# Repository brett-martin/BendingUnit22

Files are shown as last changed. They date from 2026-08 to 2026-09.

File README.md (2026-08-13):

# Bending Unit 22

BU-22 is a modular animatronic Bender-inspired clock and character display.
The Brain orchestrates operating modes, sensors, time, audio, and user input.
Independent Eyes and Mouth controllers own their LED hardware, rendering, and
precisely timed local animations.

This repository currently contains the proven Brain/Eyes breadboard tests,
draft display protocol, experimental content catalogs, and first clean v0
CircuitPython firmware slice.

## Repository map

```text
BU22_Brain/
  firmware/v0/          First Brain protocol exerciser
  tests/                Feather smoke test and reusable I2C validation suite

BU22_Eyes/
  catalogs/             Experimental expressions, animations, performances
  firmware/v0/          First clean Eyes firmware slice
  tests/                Universal I2C receiver and hardware-test backups

BU22_Mouth/
  README.md             Mouth subsystem placeholder

protocol/
  semantic_protocol_v0.md   Behavior, terminology, and ownership
  wire_protocol_v0.md       Concrete draft I2C encoding
  commands.md               Raw breadboard-only validation bytes
```

The original six-channel electrical bring-up programs are preserved under the
named Brain and Eyes test folders rather than serving as production firmware.

## Current breadboard hardware

- Adafruit Feather RP2040 acting as Brain
- Adafruit KB2040 acting as Eyes controller
- Six independent four-pixel SK9822 strands
- Three 74AHCT125 level-shifter ICs
- Independent USB power for both MCUs during development
- External regulated 5 V for level shifters and LEDs
- Shared ground, SDA, and SCL
- 4.7k I2C pull-ups to the Brain's 3.3 V rail
- Qwiic red power conductor disconnected during independent USB testing

### Eyes channel pin map

| Channel | Data | Clock |
|---:|---:|---:|
| 1 | D2 | D3 |
| 2 | D4 | D5 |
| 3 | D6 | D7 |
| 4 | D8 | D9 |
| 5 | D10 | A0 |
| 6 | A1 | A2 |

The current test assembly is physically rotated 180 degrees. Firmware keeps
content in logical orientation and applies the hardware transform at render
time.

## Proven functionality

- I2C discovery at Eyes address `0x30`
- One-byte and parameterized multi-byte commands
- Global brightness control
- Independent six-channel and 24-pixel control
- Complete 25-byte frame streaming at 10 FPS with no late frames
- Bidirectional status readback under display traffic
- Locally stored expressions and animations
- Immediate Brain interruption and STOP
- Dedicated Visor Down/Up row transitions
- Brain and Eyes disconnect/reconnect recovery
- Five-second standalone Normal fallback
- Visible missing-content development errors
- Concise action-level Eyes serial logging

See [the I2C validation index](BU22_Brain/tests/i2c_validation/README.md)
for the reusable development-board test sequence.

## Content catalogs

Expressions, animations, and performances use separate numeric ID spaces.
They remain experimental before v1. At v1, reviewed IDs become stable; later
content is appended while existing entries may improve without changing their
semantic meaning.

See [the Eyes catalog rules](BU22_Eyes/catalogs/README.md).

## Protocol documents

- [Semantic protocol v0](protocol/semantic_protocol_v0.md)
- [Wire protocol v0](protocol/wire_protocol_v0.md)
- [Raw hardware-validation commands](protocol/commands.md)

The semantic and wire documents are drafts. The raw validation bytes remain
separate so future hardware can rerun today's proven tests regardless of how
the production protocol evolves.

## Running the v0 Brain/Eyes slice

On the KB2040 Eyes `CIRCUITPY` drive, copy:

```text
BU22_Eyes/firmware/v0/code.py
BU22_Eyes/firmware/v0/config.py
BU22_Eyes/firmware/v0/content.py
```

Its `lib` directory also needs:

```text
adafruit_dotstar.mpy
adafruit_pixelbuf.mpy
```

On the Feather RP2040 Brain `CIRCUITPY` drive, copy:

```text
BU22_Brain/firmware/v0/code.py
```

The exerciser cycles expressions and animations, interrupts an animation,
tests Off and visor transitions, requests missing animation `999`, reads the
error status, and recovers with Normal.

## CircuitPython dependencies

Install the DotStar CircuitPython dependencies with:

```sh
python3 -m circup install -r requirements.txt
```

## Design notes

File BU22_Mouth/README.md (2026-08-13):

# BU-22 Mouth

The Mouth will be an independent I2C-controlled display subsystem. Its first
hardware and protocol tests will be added after the Brain-to-Eyes I2C path is
proven. Address `0x31` is reserved for it.

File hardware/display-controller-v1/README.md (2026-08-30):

# BU-22 Universal Display Controller V1

This is the hand-assembled prototype controller for either the BU-22 eyes or
mouth. Two identical boards are intended for the first complete bench system.
Pixel hardware is external: six independent SK9822/APA102-compatible LED
strings connect through four-pin JST-XH cables.

## Prototype goals

- Validate full, pixel-accurate eye and mouth animations before ordering dense
  assembled LED PCBs.
- Keep expensive LED assemblies electrically simple and reusable.
- Use through-hole parts wherever practical so five bare PCBs can be ordered
  and at least two assembled by hand.
- Keep display power distribution outside the Brain. The controller receives a
  fused 5 V branch and distributes it to its six display connectors.
- Remain usable as either Eyes (`0x30`) or Mouth (`0x31`) by changing one
  address jumper.

## Board envelope and placement

- Two-layer FR-4, 140 mm x 65 mm, with lightly rounded 3 mm corners.
- Four M3 mounting holes, 5 mm from each corner.
- Six outward-facing JST-XH outputs along the top edge.
- 5 V screw terminal, local bulk capacitors, power LED, and KB2040 USB access
  on the left side.
- Heartbeat indicator, TEST, and RESET controls along the lower-left edge.
- Four-position address selection and I2C connections along the lower edge.
- No components or connectors on the bottom side.
- Right-side silkscreen equipment mark: `BENDING UNIT 22`, `DISPLAY CONTROL
  MODULE`, and canonical serial number `2716057`, accompanied by a small
  heart/smile factory emblem no larger than the 10 mm bulk capacitor.

The 65 mm height is provisional. It fits inside the approximately 75 mm visor
opening with more than 5 mm clearance at the top and bottom. It must still be
checked against the physical print before fabrication.

## Interfaces

### LED outputs J1-J6

All six channels are independent. Pin numbering is printed on the PCB.

| Pin | Signal |
|---:|---|
| 1 | +5V display power |
| 2 | GND |
| 3 | DATA (5 V logic) |
| 4 | CLOCK (5 V logic) |

The footprint uses the common 2.50 mm XH pin row shared by the vertical
`B4B-XH-A` and right-angle `S4B-XH-A` headers. Connector body clearance must be
confirmed for the exact purchased parts before ordering.

### I2C input

`I2C IN` has both a Qwiic socket and a parallel 1x4 2.54 mm test header.
The Brain-provided 3.3 V is exposed only at the test header and is deliberately
not connected to the controller MCU. The controller uses a custom I2C object on
the socketed TX/RX pins; the KB2040's onboard STEMMA QT connector remains free.

| Signal | Destination |
|---|---|
| GND | Controller ground |
| 3V3 from Brain | Test header only |
| SDA | KB2040 TX / GP0 |
| SCL | KB2040 RX / GP1 |

No I2C pull-up resistors are fitted. The Brain is the only pull-up source.

### I2C through

`I2C THRU` carries GND, SDA, and SCL. Its Qwiic 3.3 V pin is intentionally not
connected and is labeled `NO POWER`. This permits display-controller daisy
chaining without using a display MCU as an accessory power source.

### Service input

A single four-pin JST-PH service connector is aligned vertically beside the
I2C test header. It exposes GND, the RTC-derived HEARTBEAT input, TEST, and
RESET. There is no duplicate heartbeat header.

| Pin | Signal |
|---:|---|
| 1 | GND |
| 2 | HEARTBEAT |
| 3 | TEST |
| 4 | RESET |

All socket-row GPIOs are already assigned in this six-channel design, so TEST
and RESET are exposed as useful service signals rather than claiming unused
GPIOs that do not exist.

## KB2040 GPIO assignment

This preserves the six-channel wiring proven on the breadboard.

| Function | KB2040 pin |
|---|---|
| CH1 clock / data | D3 / D2 |
| CH2 clock / data | D5 / D4 |
| CH3 clock / data | D7 / D6 |
| CH4 clock / data | D9 / D8 |
| CH5 clock / data | A0 / SCK |
| CH6 clock / data | A2 / A1 |
| I2C SCL / SDA | RX / TX |
| Address jumper network | A3 |
| Heartbeat input | D10 |
| Test button | MISO |
| Buffer enable | MOSI |

### Address selection

A 2x2 address header provides two independent vertical shunt columns while
consuming only the analog-capable A3 pin. A resistor network produces four
distinct ADC levels for firmware to decode. The physical user interface is:

| Left/Eyes column | Right/Mouth column | Intended role/address |
|---|---|---|
| Closed | Open | Eyes `0x30` |
| Open | Closed | Mouth `0x31` |
| Open | Open | Development `0x33` |
| Closed | Closed | Spare display `0x32` |

Display Controller Rev D does not implement this orientation correctly; its
fabricated copper requires horizontal-row shunts as a temporary workaround.
See `hardware/display-controller-rev-d/ERRATA.md` E2.

The ADC thresholds must be verified on assembled hardware before this becomes
the production address scheme.

## Fail-dark behavior

The three AHCT125 output-enable pins are pulled high at 5 V, disabling every
LED signal during reset. A 2N3904 controlled by KB2040 MOSI pulls `OE_N` low
only after firmware has initialized and sent a black frame. The 5 V enable net
never connects directly to a 3.3 V GPIO.

No separate 5 V sense is required in Revision A. With display power absent the
AHCT devices are unpowered. When 5 V appears, its hardware pull-up immediately
holds `OE_N` disabled until firmware explicitly enables the outputs.

## Power and service rules

- J7 accepts regulated 5 V through a 5.08 mm two-pin screw terminal.
- The external 5 V branch is fused outside this PCB.
- The controller powers the KB2040 through `RAW` and powers all six LED ports.
- Do not power LED strips from a computer USB port.
- During early bring-up, disconnect I2C/heartbeat before USB-programming an
  otherwise unpowered Brain. Simultaneous wall power and USB must be validated
  before treating it as a supported service mode.

## Status and controls

- Green 3 mm LED: external 5 V present.
- Red 3 mm LED: hardware heartbeat input.
- TEST button: local diagnostic-mode override.
- RESET button: KB2040 reset.
- Two address shunts select Eyes, Mouth, Spare, or Development addresses.

## Fabrication status

Revision A is an engineering layout, not yet released for ordering. Routing is
in progress: the 5 V distribution network, rear ground plane, twelve
resistor-to-display output runs, and the first clean automatic signal-routing
pass are complete. Forty-one ratsnest connections remain for deliberate manual
routing around the dense MCU/buffer/control area. Before fabrication:

1. Measure the actual 5.08 mm screw terminal body.
2. Confirm the exact Adafruit Qwiic connector footprint/part number on hand.
3. Check the 140 x 65 mm outline against the physical visor.
4. Complete routing and obtain a clean KiCad DRC.
5. Print the board 1:1 and physically place the KB2040, DIP sockets, XH
   connectors, and terminal on the paper check.

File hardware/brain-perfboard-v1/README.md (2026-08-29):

# BU-22 Brain Perfboard V1

Prototype carrier for the BU-22 Brain. This version is intended for a 24 x 56
hole stripboard with copper strips running in the 56-hole direction.

## Design intent

- Adafruit Feather RP2040 is socketed and removable.
- Adafruit Audio FX Sound Board + 2x2 W Amp, 16 MB is socketed and removable.
- Adafruit DS3231 Precision RTC is socketed and removable.
- No display LED current passes through this board.
- The Feather is powered from either USB-C or an external regulated 5 V input.
- External 5 V is isolated from Feather USB VBUS by a Schottky diode.
- The RTC SQW output is the system heartbeat source.
- All external wiring uses 2.54 mm headers except the Feather's built-in Qwiic
  connector.

## Board orientation

View all coordinates from the component side, with the 56-hole dimension left
to right and the long copper strips also running left to right. Columns are
numbered 1-56. Rows are lettered A-X.

The recommended placement is shown in `component-layout.svg`. The Audio FX
board occupies the far-left position. The Feather is central so its GPIO is
close to the RTC, heartbeat circuitry, buttons, antenna, sensor, and spare-I/O
headers on the right. Both long modules are rotated so their long axes run from
top to bottom, putting each pin on a different copper strip. Their USB
connectors remain exposed at the lower board edge. The RTC SQW/heartbeat area
sits directly above the button header.

The exact socket coordinates, copper cuts, and point-to-point jumper list are
in `cuts-and-jumpers.md`. Do not infer copper-side coordinates directly from
the component-side drawing: the copper side is horizontally mirrored.

For readable assembly, the wiring is also separated into four maps:

- `brain-layer-power.svg`
- `brain-layer-audio-control.svg`
- `brain-layer-buttons.svg`
- `brain-layer-rtc-heartbeat.svg`
- `brain-layer-antenna-sensor.svg`

The spare header is intentionally omitted from these maps for now.
These separated maps are the primary assembly references; `stripboard-map.svg`
is retained only as a combined connectivity overview.

## Functional wiring

### Power

| Net | Connection |
|---|---|
| EXT_5V | External regulated 5 V screw terminal/header positive |
| GND | External input negative, Feather GND, Audio FX GND, RTC GND, all headers |
| LOGIC_5V | D1 cathode, Feather USB pin, Audio FX VIN |
| 3V3 | Feather 3.3 V, RTC VIN, heartbeat pull-up, sensor/header logic power |

Power path:

`EXT_5V -> D1 (1N5817) -> LOGIC_5V -> Feather USB pin`

The diode's banded cathode faces `LOGIC_5V` / the Feather. When USB-C is
connected, D1 prevents USB power from flowing back into the external 5 V
terminal. The Audio FX board is powered from `LOGIC_5V`, so it is available
under either USB or external power.

Do not connect an external 5 V supply to the Feather 3.3 V pin or BAT pin.

### I2C and RTC

| Signal | Feather | RTC | External |
|---|---|---|---|
| SDA | SDA / GP2 | SDA | Feather Qwiic |
| SCL | SCL / GP3 | SCL | Feather Qwiic |
| 3.3 V | 3V | VIN | Feather Qwiic |
| Ground | GND | GND | Feather Qwiic |
| Heartbeat | D13 / GP13 | SQW | J_HB pin 1 |

R_HB is an optional 10 kOhm pull-up from `HEARTBEAT` to 3.3 V. Populate it for
the DS3231 SQW open-drain output unless the exact RTC module is confirmed to
provide its own SQW pull-up. The RTC's SDA/SCL pull-ups are separate and do not
pull up SQW.

### Audio FX UART

| Signal | Feather | Audio FX |
|---|---|---|
| Brain TX | TX / GP0 | RX |
| Brain RX | RX / GP1 | TX |
| Activity | D24 / GP24 | ACT (active low) |
| Reset | D25 / GP25 | RST (active low) |
| UART mode | Ground | UG |
| Power | LOGIC_5V | VIN |
| Ground | Ground | Ground |

The amplifier version's speaker outputs go directly to the two speaker
headers. Do not tie either speaker lead to ground.

### Buttons

J_BUTTONS is an 8-pin 2.54 mm header. The button daughterboard shares ground;
firmware uses internal pull-ups.

| Pin | Signal | Feather |
|---:|---|---|
| 1 | Ground | GND |
| 2 | Button 5; function not yet identified | D4 / GP6 |
| 3 | Down / logical button 4 | D5 / GP7 |
| 4 | Up / logical button 3 | D6 / GP8 |
| 5 | Enter / logical button 2 | D9 / GP9 |
| 6 | Mode / logical button 1 | D10 / GP10 |
| 7 | Button 6 | D11 / GP11 |
| 8 | Button 7 | D12 / GP12 |

### Other I/O

| Header | Pinout | Feather |
|---|---|---|
| J_HB | 1 Heartbeat, 2 Ground | D13 / GP13 |
| J_ANT | 1 Red, 2 Green, 3 Blue/spare, 4 Ground | A0/GP26, A1/GP27, A2/GP28 |
| J_SENSOR | 1 3.3 V, 2 Ground, 3 Signal, 4 Spare | A3/GP29, spare D25/GP25 if audio reset is omitted |
| J_SPARE | 1 SCK/GP18, 2 MO/GP19, 3 MI/GP20, 4 D25/GP25, 5 Ground | as labeled |

Use a resistor or transistor driver appropriate to the final antenna LED. The
header signals themselves are 3.3 V GPIO and are not intended to power a high
current LED directly.

## Parts added by this carrier

| Ref | Part | Notes |
|---|---|---|
| D1 | 1N5817 Schottky diode | External 5 V isolation |
| R_HB | 10 kOhm, through-hole | Optional SQW pull-up to 3.3 V |
| C1 | 100 uF, >= 10 V electrolytic | Near external input / Audio FX VIN |
| C2 | 100 nF ceramic | Near Audio FX VIN |
| J_PWR | 2-pin screw terminal or 2.54 mm header | 5 V, Ground |
| J_BUTTONS | 1x8 2.54 mm header | Ground + seven buttons |
| J_HB | 1x2 2.54 mm header | Heartbeat + ground |
| J_ANT | 1x4 2.54 mm header | RGB/spare + ground |
| J_SENSOR | 1x4 2.54 mm header | 3.3 V, ground, signal, spare |
| J_SPARE | 1x5 2.54 mm header | Spare GPIO + ground |
| SPK_L, SPK_R | 1x2 headers or screw terminals | Floating amplified speaker pairs |

## Assembly sequence

1. Place the unpowered modules over the printed plan and confirm their real
   header spacing before drilling/cutting any track.
2. Mark the component-side board origin and transfer all socket positions.
3. Fit female sockets and verify that all three modules insert without force.
4. Make strip cuts beneath socket regions before installing sockets.
5. Meter every adjacent socket pin for isolation.
6. Install wire links and passive parts, but leave all modules removed.
7. Verify D1 polarity and continuity from external 5 V to LOGIC_5V.
8. Apply current-limited 5 V and verify LOGIC_5V before inserting modules.
9. Insert only the Feather; test USB and external-power switchover.
10. Insert RTC and verify I2C plus SQW heartbeat.
11. Insert Audio FX last; test UART, ACT, reset, then speakers at low volume.

## Important physical check

The layout intentionally treats the RTC and Audio FX modules as socketed
rectangles. Before soldering, place the exact boards on the stripboard and
transfer their real header locations. Adafruit revisions preserve electrical
pin functions but the available header holes and USB/terminal hardware can
change the practical socket footprint.

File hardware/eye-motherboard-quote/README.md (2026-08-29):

# BU-22 eye motherboard — quote-only outline

This is a mechanical pricing sample, not a production eye motherboard.

- Nominal board size: 174 × 83 mm
- Corner radius: approximately 30 mm
- Construction: two-layer FR-4
- Mounting holes: four 3.2 mm NPTH holes
- Functional circuitry: none
- Assumed visible visor opening: 166 × 75 mm
- Assumed outer visor size: 182 × 91 mm

The dimensions are inferred from the existing visor drawing and must be
verified against the physical printed visor before any functional motherboard
is designed or ordered.

Upload the fabrication ZIP only to obtain a bare-PCB quote. Do not order this
board as the final motherboard.

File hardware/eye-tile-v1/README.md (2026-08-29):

# BU-22 Eye Tile V1 — Locked Design Direction

This document records the component-agnostic architecture for the first
manufactured BU-22 eye tile. Exact LED, capacitor, connector, and assembly
part numbers remain open until sourcing and hardware comparison tests are
complete.

## Locked display architecture

- The complete eye display is `36 x 16` pixels.
- It is assembled from four identical `9 x 16` eye tiles arranged
  horizontally.
- Nominal pixel pitch is approximately 4 mm, subject only to final mechanical
  verification against the visor and diffuser.
- A tile is electrically self-contained as one display channel.
- Four tiles provide four independent controller channels while forming one
  continuous display surface.
- Pixel mapping and physical orientation will be normalized in display
  firmware, so the Brain remains independent of tile wiring order.

## Mechanical and optical rules

- LEDs occupy nearly the entire front surface.
- Left and right edges contain no mounting holes, connectors, or protruding
  components; identical tiles must meet with a consistent pixel pitch across
  each seam.
- Connectors and mounting features belong above or below the active LED area,
  or on the rear.
- The front remains clear for a flush egg-crate light baffle and flat diffuser.
- The board and baffle must provide repeatable mechanical registration so the
  four grids align as one `36 x 16` matrix.
- The eye motherboard provides the visor-sized mounting structure and tile
  sockets; the expensive LED tiles remain simple and replaceable.

## Electrical rules

- The tile uses a clocked, individually addressable RGB LED architecture with
  5 V, ground, clock, and data.
- APA102-2020 and SK9822-EC20 remain candidate components; the exact device is
  not locked yet.
- Use a four-layer PCB with robust 5 V and ground planes.
- Route the pixels as a compact serpentine chain.
- Size tile power entry, connector contacts, planes, and traces for one full
  `9 x 16` tile independently of the other tiles.
- Provide accessible 5 V and ground test pads at the power entry and far end.
- Provide clock/data test pads at useful chain boundaries.
- No display-controller, level-shifter, MCU, or unrelated electronics belong
  on the LED tile.

## Capacitor strategy

- Do not populate a capacitor at every LED in the initial assembly.
- Include one optional, rear-side `0603` decoupling-capacitor footprint for
  every pixel.
- Mark all per-pixel capacitor positions DNP for the initial build.
- Arrange the optional footprints so they can be hand-soldered after assembly.
- Include shared distributed-capacitance footprints, nominally 10–47 uF.
- Include an optional 220–470 uF bulk-capacitor footprint near power entry.
- The board must have adequate power integrity without relying on populated
  per-pixel capacitors; optional capacitors are a diagnostic and refinement
  mechanism, not a substitute for proper planes.

The planned validation sequence is:

1. Test with bulk/distributed capacitance only.
2. If needed, populate every fourth or eighth per-pixel footprint.
3. Populate all per-pixel footprints only if measurements or visible behavior
   justify it.

## Reference concept

The Adafruit DotStar High Density 8x8 Grid (product 3444) is the conceptual
reference for dense LED placement, edge-aware tiling, four-layer power
distribution, and operation without populated per-pixel capacitors. The BU-22
tile is a new design with different geometry, pitch, connectors, channel
partitioning, mounting, and optical requirements.

## Decisions intentionally left open

- APA102-2020 versus SK9822-EC20
- Exact LED manufacturer and assembly source
- Exact connector family and rear/top/bottom orientation
- Final bulk and distributed capacitor values
- Whether any optional per-pixel capacitors are populated in production
- Final board outline after mechanical measurements

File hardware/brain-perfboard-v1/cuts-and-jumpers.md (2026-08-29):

# BU-22 Brain Stripboard Cut and Jumper Plan

This is the exact first-pass hole map for a 56-column by 24-row stripboard.
Coordinates are always viewed from the **component side**:

- Columns: `1` through `56`, left to right
- Rows: `A` through `X`, top to bottom
- Copper strips: run left to right
- USB edge: row `X`

When working on the copper side, mirror the columns. Mark the component-side
origin permanently before turning the board over.

## Socket coordinates

### Audio FX 16 MB + 2x2 W amplifier - far left

The Audio FX module is rotated with its USB connector toward row X.

| Module header | Stripboard column | Occupied rows |
|---|---:|---|
| GPIO / trigger row | 4 | H through U |
| Control / UART row | 12 | H through U |

Audio pin map:

| Row | Col 4 GPIO header | Col 12 control header |
|---|---|---|
| H | GND | GND |
| I | ACT | L line out |
| J | Trigger 10 | R line out |
| K | Trigger 9 | GND |
| L | Trigger 8 | CS - do not connect |
| M | Trigger 7 | Volume - |
| N | Trigger 6 | Volume + |
| O | Trigger 5 | UG - connect to GND for UART |
| P | Trigger 4 | RX - from Brain TX |
| Q | Trigger 3 | TX - to Brain RX |
| R | Trigger 2 | PB |
| S | Trigger 1 | USB BUS - leave unconnected |
| T | Trigger 0 | GND |
| U | RST | VIN / LOGIC_5V |

The module's built-in speaker terminal blocks remain accessible; the carrier
does not duplicate them.

### Feather RP2040 Brain - center

The Feather is rotated with USB-C toward row X.

| Feather header | Stripboard column | Occupied rows |
|---|---:|---|
| 1x16 / analog side | 17 | F through U |
| 1x12 / digital side | 25 | F through Q |

| Row | Col 17, 1x16 side | Col 25, 1x12 side |
|---|---|---|
| F | D4 / Button 1 | SDA |
| G | TX / GP0 | SCL |
| H | RX / GP1 | D5 / Button 2 |
| I | MISO / GP20 | D6 / Button 3 |
| J | MOSI / GP19 | D9 / Button 4 |
| K | SCK / GP18 | D10 / Button 5 |
| L | D25 / Audio reset | D11 / Button 6 |
| M | D24 / Audio activity | D12 / Button 7 |
| N | A3 / GP29 / Sensor | D13 / Heartbeat input |
| O | A2 / GP28 / Antenna blue | USB / VBUS |
| P | A1 / GP27 / Antenna green | EN |
| Q | A0 / GP26 / Antenna red | BAT |
| R | GND | - |
| S | 3.3 V | - |
| T | 3.3 V | - |
| U | RESET | - |

### DS3231 Precision RTC - upper right

Use the original Adafruit header-only DS3231 breakout orientation. The 1x8
header is vertical at column 31.

| Coordinate | RTC signal |
|---|---|
| 31-E | 3.3 V / VIN |
| 31-F | GND |
| 31-G | SCL |
| 31-H | SDA |
| 31-I | VBAT - no carrier connection |
| 31-J | 32 kHz - no carrier connection |
| 31-K | SQW / HEARTBEAT |
| 31-L | RTC reset - no carrier connection |

If the actual RTC is the newer STEMMA QT revision, do not force it into this
socket. Use the Feather Qwiic connector and a two-pin SQW/GND pigtail instead.

## External headers

All headers are vertical so every pin begins on a different copper strip.

| Header | Coordinates, top to bottom | Pin order |
|---|---|---|
| J_BUTTONS | 38-N through 38-U | GND, B1, B2, B3, B4, B5, B6, B7 |
| J_HEART | 42-N through 42-O | HEARTBEAT, GND |
| J_ANT | 46-N through 46-Q | RED, GREEN, BLUE/SPARE, GND |
| J_SENSOR | 50-N through 50-Q | 3.3 V, GND, SIGNAL, SPARE |
| J_SPARE | 54-N through 54-R | GP18, GP19, GP20, GP25/shared, GND |
| J_POWER | 54-D through 54-E | External +5 V, GND |

`GP25/shared` is connected to Audio FX reset in this revision. It is exposed
for measurement or alternate firmware, not for simultaneous unrelated use.

## Copper cuts

### Continuous isolation grooves

Cut and verify these copper strips before installing sockets. A narrow rotary
tool groove is acceptable for the continuous cuts; otherwise use a proper
stripboard cutter at every listed row.

| Cut column | Rows | Purpose |
|---:|---|---|
| 14 | A-X | Isolate Audio FX zone from Feather zone |
| 27 | A-X | Isolate Feather zone from RTC/I/O zone |
| 35 | D-U | Isolate RTC zone from button zone |
| 40 | D-U | Isolate buttons from heartbeat header |
| 44 | D-U | Isolate heartbeat from antenna header |
| 48 | D-U | Isolate antenna from sensor header |
| 52 | D-U | Isolate sensor from spare/power header |

### Cuts between module socket rows

| Cut column | Rows | Purpose |
|---:|---|---|
| 8 | H-U | Separate the two Audio FX socket rows |
| 21 | F-U | Separate the two Feather socket rows |

After cutting, check every pair of adjacent zones with continuity mode. There
must be no continuity across any cut.

## Insulated jumper list

The notation `12-Q -> 17-H` means an insulated wire from column 12, row Q to
column 17, row H.

## Shared power buses

The separated layer drawings use three deliberately simple horizontal buses.
These supersede the earlier daisy-chain ground depiction:

| Bus | Row and extent | Required bridges |
|---|---|---|
| Protected LOGIC_5V | Row C, columns 3-51 | Bridge the cuts at columns 14 and 27 |
| 3.3 V | Row V, columns 15-51 | Bridge the cut at column 27 |
| Ground | Row W, columns 3-55 | Bridge the cuts at columns 14 and 27 |

The bridges are short insulated wires placed around the cut holes. Never rely
on a cut copper strip to carry a bus through the cut.

Connect the following points vertically to the buses:

| Bus | Connection points |
|---|---|
| LOGIC_5V | Audio VIN 12-U; Feather VBUS 25-O |
| 3.3 V | Feather 17-S; RTC 31-E; Sensor 50-N; heartbeat pull-up |
| Ground | Audio 4-H and 12-T; Feather 17-R; RTC 31-F; Buttons 38-N; Heartbeat 42-O; Antenna 46-Q; Sensor 50-O; Power 54-E |

### Audio UART/control

| From | To | Net |
|---|---|---|
| 12-Q | 17-H | Audio TX -> Brain RX |
| 12-P | 17-G | Brain TX -> Audio RX |
| 4-I | 17-M | Audio ACT -> Brain D24 |
| 4-U | 17-L | Brain D25 -> Audio RST |
| 12-O | GND bus | Audio UG held low for UART mode |
| 12-U | LOGIC_5V | Audio VIN |
| 12-T | GND bus | Audio ground |
| 4-H | GND bus | Audio ground |

### RTC and I2C

| From | To | Net |
|---|---|---|
| 31-E | 17-S | RTC 3.3 V |
| 31-F | GND bus | RTC ground |
| 31-G | 25-G | RTC SCL -> Feather SCL |
| 31-H | 25-F | RTC SDA -> Feather SDA |
| 31-K | 25-N | RTC SQW -> Feather heartbeat input |
| 31-K | 42-N | RTC SQW -> external heartbeat |

Install the optional heartbeat pull-up below the RTC:

- jumper `31-K -> 33-N`
- 10 kOhm resistor from `33-N -> 33-R`
- jumper `33-R -> 17-S` (3.3 V)

The DS3231 SQW output is open drain and requires a pull-up. This resistor is
independent of the RTC board's SDA/SCL pull-ups.

### Buttons

| Header coordinate | Feather coordinate | Net |
|---|---|---|
| 38-N | GND bus | Button common |
| 38-O | 17-F | Button 1 / D4 |
| 38-P | 25-H | Button 2 / D5 |
| 38-Q | 25-I | Button 3 / D6 |
| 38-R | 25-J | Button 4 / D9 |
| 38-S | 25-K | Button 5 / D10 |
| 38-T | 25-L | Button 6 / D11 |
| 38-U | 25-M | Button 7 / D12 |

### Antenna and sensor

| Header coordinate | Feather coordinate | Net |
|---|---|---|
| 46-N | 17-Q | Antenna red / A0 |
| 46-O | 17-P | Antenna green / A1 |
| 46-P | 17-O | Antenna blue or spare / A2 |
| 46-Q | GND bus | Antenna ground |
| 50-N | 17-S | Sensor 3.3 V |
| 50-O | GND bus | Sensor ground |
| 50-P | 17-N | Sensor signal / A3 |
| 50-Q | 17-I | Sensor spare / GP20 |

### Spare header

| Header coordinate | Feather coordinate | Net |
|---|---|---|
| 54-N | 17-K | GP18 / SCK |
| 54-O | 17-J | GP19 / MOSI |
| 54-P | 17-I | GP20 / MISO |
| 54-Q | 17-L | GP25 / shared Audio reset |
| 54-R | GND bus | Ground |

## Power wiring

1. Install D1, a 1N5817 Schottky diode, with its **anode** connected to
   `J_POWER +5 V` at 54-D.
2. The banded **cathode** lands at `51-D` and becomes `LOGIC_5V`.
3. Connect `51-D -> 51-C`, feeding the protected LOGIC_5V bus on row C.
4. Bridge the row-C cuts at columns 27 and 14 with insulated wire.
5. Connect the LOGIC_5V bus to Feather USB/VBUS at 25-O and Audio VIN at 12-U.
6. Connect J_POWER ground at 54-E to the row-W ground bus.
7. Connect Feather ground at 17-R to the row-W ground bus.
8. Place 100 uF from LOGIC_5V to ground near the Audio FX module.
9. Place 100 nF from LOGIC_5V to ground near Audio VIN.

This matches the display-controller isolation concept: external 5 V can power
the Feather through its USB/VBUS pin, while USB-C at the Feather supplies the
logic rail without feeding the external input through D1.

## Before inserting modules

1. Confirm every copper cut visually under magnification.
2. Check resistance from LOGIC_5V to ground; it must not be a short.
3. Check that no Audio socket pin is shorted to the opposing Audio socket row.
4. Check that no Feather socket pin is shorted to the opposing Feather row.
5. Apply current-limited 5 V with all modules removed.
6. Verify diode polarity and LOGIC_5V voltage.
7. Remove power, insert only the Feather, and test external/USB operation.
8. Add RTC, then Audio FX, one module at a time.

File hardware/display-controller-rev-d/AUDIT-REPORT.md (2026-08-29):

# BU-22 Display Controller Rev D — release audit

> **Assembly erratum:** The `+` silkscreen marks for D1 and D2 are on the
> wrong side. The left square pad 1 is cathode/GND; the right round pad 2 is
> anode/positive. See [ERRATA.md](ERRATA.md) before assembly.

Audit date: 2026-08-18

## Result

**PASS for bare-PCB fabrication.**

- KiCad 10 native DRC: 0 violations
- KiCad connectivity: 0 unconnected items/pads
- Independent 0.20 mm copper geometry audit: 0 front-layer conflicts,
  0 back-layer conflicts
- Footprint errors: 0
- Board outline: closed, 125.0 × 55.0 mm
- Four 3.20 mm non-plated mounting holes present
- Four copper layers present and exported
- All three copper zones refilled before export

## Electrical checks

- J1–J6 use the requested input order: pin 1 GND, pin 2 CLOCK,
  pin 3 DATA, pin 4 SYSTEM_5V.
- U1–U3 are 74AHCT125 SOIC-14 footprints; pin 14 is LOGIC_5V and pin 7
  is GND.
- D3 isolation polarity is SYSTEM_5V (anode/pad 2) to LOGIC_5V
  (cathode/pad 1).
- D1 and D2 use the KiCad T-1 convention: pad 1 cathode/GND, pad 2 anode.
- Q1 footprint/net order is emitter/GND, base/ENABLE_BASE,
  collector/OE_N for the selected inline 2N3904.
- I2C headers intentionally omit 3.3 V on pin 2. GND, SDA and SCL remain.
- Internal layer 1 is GND. Internal layer 2 is protected LOGIC_5V.
- External SYSTEM_5V remains on routed outer-layer copper.

## BOM/footprint checks

- 74AHCT125S14-13: SOIC-14 footprint matches the ordered package.
- 2N3904: inline TO-92 footprint matches the ordered through-hole package
  and its E-B-C lead order.
- R1–R20: 0805 footprints match the ordered resistor series.
- C1–C3: 0805 footprints match the ordered 100 nF capacitors.
- C4/C5: polarized radial through-hole footprints; polarity is marked.
- J1–J6: JST-XH B4B vertical through-hole footprints.
- J8/J9: JST-SH/Qwiic 4-position SMD footprints.
- J10/J11: JST-PH vertical through-hole footprints.
- JP1: 2×2, 2.54 mm through-hole header.
- MCU sockets: two 1×13, 2.54 mm through-hole rows for the KB2040.

## Manufacturing package

The JLCPCB ZIP contains 12 files: four copper Gerbers, two solder masks,
two silkscreens, board outline, plated drill, non-plated drill, and Gerber
job file. This release is intentionally for bare-PCB/manual assembly.

Package SHA-256:

`c70fd736b77c3282ce98b01e3636109fb81fb3cbc430332e36badc5e3fcaaf1a`

## Important order setting

Select **4 layers**. A two-layer order is not electrically equivalent because
the internal GND and LOGIC_5V planes are part of Rev D.

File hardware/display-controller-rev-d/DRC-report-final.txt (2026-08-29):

** Drc report for BU-22-Display-Controller-Rev-D.kicad_pcb **
** Created on 2026-08-18T12:08:57 **
** Report includes: Errors, Warnings, Exclusions **

** Found 0 DRC violations **

** Found 0 unconnected pads **

** Found 0 Footprint errors **

** Ignored checks **
    - Footprint has no courtyard defined
    - Track endpoint not centered on via
    - Tuning profile track geometries
    - Footprint doesn't match symbol's footprint filters
    - Footprint component type doesn't match footprint pads

** End of Report **

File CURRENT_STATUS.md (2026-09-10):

# BU-22 current project status

Last updated: 2026-09-09

## Active hardware

- `CTRL-RD-01`: first hand-assembled Display Controller Rev D. Passive power
  distribution, five-second output-enable transition, static output levels,
  and dynamic mouth-tile operation pass across CH1–CH6 after correcting the
  reversed CH1–CH4 firmware clock/data mapping. Its KB2040 UID is
  `DF63CC284F66402B` and its current development role is Mouth. See
  `hardware/bringup/CTRL-RD-01.md`.
- `CTRL-RD-02`: second Display Controller Rev D assembled and connected to one
  `9 x 16` eye tile. Static levels and dynamic eye-tile operation pass across
  CH1–CH6 with the corrected mapping. No obvious board or solder flaw was
  visible under microscope inspection. Its KB2040 UID is
  `DF63CC284F214629`. See
  `hardware/bringup/CTRL-RD-02.md`.
- `BRAIN-PERF-01`: prototype Brain perfboard assembled. I2C discovery, RTC
  read/set, configured 1 Hz SQW heartbeat, and Audio FX UART/list/play-command
  tests have passed. Physical NeoPixel, button, and audible Audio FX tests also
  pass. Raw sensor response, close interrupt assertion, and the physical red
  antenna outputs and USB/external-5 V isolation also pass. Sensor interrupt
  integration is intentionally deferred. An integrated scan with both Rev D
  targets also passed, finding Eyes `0x30`, Mouth `0x31`, VCNL4200 `0x51`, and
  DS3231 `0x68`. See
  `hardware/bringup/BRAIN-PERF-01.md`.

## Active firmware

- Universal Rev D standalone controller test:
  `BU22_Eyes/tests/display_controller_rev_d_bringup/`
- Rev D fail-dark, jumper-addressed I2C target scan test:
  `BU22_Eyes/tests/display_controller_rev_d_i2c_target/`
- Rev D all-channel clock/data output exerciser:
  `BU22_Eyes/tests/display_controller_rev_d_output_exerciser/`
- Rev D 5x11 tooth-module visual test:
  `BU22_Mouth/tests/display_controller_rev_d_tooth_module/`
- Rev D deliberately slow valid-DotStar mouth test:
  `BU22_Mouth/tests/display_controller_rev_d_slow_dotstar/`
- Rev D 9x16 eye-tile visual test:
  `BU22_Eyes/tests/display_controller_rev_d_eye_tile/`
- Rev D 9x16 repeating eye-blink animation test:
  `BU22_Eyes/tests/display_controller_rev_d_eye_blink/`
- Rev D six-channel CircuitPython DotStar performance benchmark:
  `BU22_Eyes/tests/display_controller_rev_d_dotstar_benchmark/`
- Rev D one-GPIO-at-a-time physical output locator:
  `BU22_Eyes/tests/display_controller_rev_d_gpio_locator/`
- Rev D CH6 full-array LED validation:
  `BU22_Eyes/tests/display_controller_rev_d_ch6_array_test/`
- Rev D combined CH5/CH6 hardware-SPI full-array validation:
  `BU22_Eyes/tests/display_controller_rev_d_spi1_array_test/`
- Rev D geometry-aware 10 FPS tiled line scan:
  `BU22_Eyes/tests/display_controller_rev_d_tiled_line_scan/`
- Rev D stored-frame I2C animation receiver:
  `BU22_Eyes/tests/display_controller_rev_d_i2c_animation/`
- Brain perfboard bring-up test:
  `BU22_Brain/tests/brain_board_bringup/`
- Rev D half-scale static Eyes I2C test:
  `BU22_Eyes/tests/display_controller_rev_d_static_i2c/`
- Rev D half-scale static Mouth I2C test:
  `BU22_Mouth/tests/display_controller_rev_d_static_i2c/`

The controller test source no longer enables the KB2040 heartbeat input's
internal pull-up. A disconnected heartbeat LED should therefore remain off.
Confirm that this corrected source is deployed before interpreting the LED.

## Immediate next steps

1. Continue firmware development with each complete half-size array on one
   hardware-SPI chain: 288 Eyes pixels and 165 Mouth pixels both pass at 4 MHz
   on the combined CH5-clock/CH6-data SPI1 path. The earlier dual-chain test
   passed visually in sync at 4 MHz, supporting a two-hardware-SPI-channel
   target for Rev E. On Rev D, SPI0 is physically on CH4 and SPI1 uses CH5
   clock plus CH6 data.
   Geometry-aware horizontal and vertical line scans also pass visually at
   10 FPS across the 18x16 Eyes and 15x11 Mouth layouts.
2. Continue the successful stored-frame Eyes/Mouth command path into the
   simulator export workflow and higher-level Brain behavior. Brain v0.12 now
   loops an eight-second performance at 10 FPS, sends matching tagged I2C frame
   commands to both controllers, and both render their complete half-size
   arrays locally over 4 MHz SPI1.
3. Develop compiled or hardware-assisted controller output to meet the
   six-channel 10 FPS animation target; this is separate from hardware
   validation.
4. Optionally measure Brain I2C pull-up strength. Sensor interrupt integration
   is intentionally deferred.

## Two-Mac workflow

1. Pull with `git pull --ff-only` before beginning work.
2. Work from repository files and copy them to `CIRCUITPY` only for deployment.
3. Record physical results under `hardware/bringup/`.
4. Commit and push before moving to the other Mac.
5. Avoid editing the same file concurrently on both machines.

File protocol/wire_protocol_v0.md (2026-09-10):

# BU-22 display wire protocol — draft v0

This document encodes the actions in `semantic_protocol_v0.md` into a compact
I2C protocol for Eyes and Mouth. It is the first implementation draft, not a
frozen public API.

## Physical assumptions

- I2C controller: Brain
- I2C targets: display modules
- Default Eyes address: `0x30`
- Default Mouth address: `0x31`
- Bus speed: 100 kHz initially
- SDA and SCL pulled up once to the Brain's 3.3 V rail
- All modules share ground
- Modules are not powered through the Qwiic power conductor during USB testing

Configurable address pads may alter the final addresses. The defaults above
remain the development and documentation addresses.

## Encoding conventions

- Each Brain write is one complete I2C transaction.
- Byte 0 is always the command.
- Remaining bytes are command arguments.
- Multi-byte integers are unsigned and big-endian.
- Identifiers are 16-bit values unless stated otherwise.
- Brightness is `0..255`.
- RGB colors are three bytes: red, green, blue.
- Boolean values are `0` or `1`.
- Text is UTF-8, limited initially to printable ASCII for the built-in font.
- Packets are limited to 32 bytes in v0.
- No packet length field is needed because I2C preserves transaction boundaries.
- No application checksum is included in v0. I2C already provides per-byte ACK
  and the module rejects malformed transaction lengths.

## Request tag

Every visual activity command includes a one-byte `tag` selected by the Brain.
The display echoes the most recently accepted tag in status.

The Brain normally increments the tag modulo 256. The tag lets it distinguish
completion of the requested activity from stale status belonging to an older
activity. A tag is an identifier, not a queue position.

Settings, message-transfer, identify, and maintenance commands do not require a
tag because they are applied immediately and are not timed visual activities.

## Command summary

### Immediate visual control — `0x10..0x1F`

| Byte | Command | Arguments |
|---:|---|---|
| `0x10` | `SHOW_NORMAL` | `tag` |
| `0x11` | `SHOW_EXPRESSION` | `tag, expression_id:u16` |
| `0x12` | `PLAY_ANIMATION` | `tag, animation_id:u16` |
| `0x13` | `PLAY_PERFORMANCE` | `tag, performance_id:u16` |
| `0x14` | `STOP` | `tag` |
| `0x15` | `SET_OFF` | `tag` |
| `0x16` | `PLAY_VISOR_DOWN` | `tag, step_ms:u16` |
| `0x17` | `PLAY_VISOR_UP` | `tag, step_ms:u16` |
| `0x18` | `PLAY_ANIMATION_TIMED` | `tag, animation_id:u16, entry_ms:u16, hold_ms:u16, exit_ms:u16` |

Every command in this group immediately interrupts the current visual activity.
There is no display-side command queue and interrupted activities do not resume.

`SHOW_NORMAL` and `STOP` both finish at Normal. They remain separate semantic
commands so status can distinguish a requested visual state from an emergency
or mode-change cancellation.

`PLAY_ANIMATION_TIMED` uses the animation's authored entry and exit sequences,
but retimes each phase to the supplied millisecond duration. Controllers sample
no faster than the catalog's global maximum display FPS, hold or skip authored
frames deterministically, and always display each phase's final frame.

### Clock and message — `0x20..0x2F`

| Byte | Command | Arguments |
|---:|---|---|
| `0x20` | `SHOW_CLOCK` | `tag, hour, minute, flags` |
| `0x21` | `UPDATE_CLOCK` | `hour, minute` |
| `0x22` | `SHOW_MESSAGE` | `tag, flags` |
| `0x23` | `MESSAGE_BEGIN` | `total_length:u8` |
| `0x24` | `MESSAGE_CHUNK` | `offset:u8, data:0..30 bytes` |
| `0x25` | `MESSAGE_COMMIT` | `expected_length:u8` |
| `0x26` | `MESSAGE_ABORT` | none |
| `0x27` | `RESET_MESSAGE` | none |

Clock flags:

| Bit | Meaning |
|---:|---|
| 0 | Colon blinks locally when set; remains solid when clear |
| 1 | Render in 24-hour format when set; 12-hour format when clear |
| 2–7 | Reserved, send zero |

Hours use display-ready local time from the Brain. Valid ranges are hour
`0..23` and minute `0..59`. The Brain owns RTC, timezone, DST, and the user's
12/24-hour preference; Eyes performs only the requested rendering.

Message flags:

| Bit | Meaning |
|---:|---|
| 0 | Repeat scrolling |
| 1 | Hold final frame instead of returning to the beginning |
| 2–7 | Reserved, send zero |

The persisted message is at most 128 bytes. Replacement is atomic:

1. `MESSAGE_BEGIN(total_length)` creates a temporary buffer.
2. One or more `MESSAGE_CHUNK(offset, data)` writes populate it.
3. `MESSAGE_COMMIT(expected_length)` validates, persists, and activates it as
   the stored message.
4. Any validation failure retains the previous stored message.
5. `MESSAGE_ABORT` discards the temporary buffer.

`RESET_MESSAGE` restores `Please Insert Girder`.

Clock- or message-specific appearance uses `SET_TEMP_BRIGHTNESS` and
`SET_TEMP_COLOR` before entering the mode, followed by the corresponding clear
commands when the override ends. This avoids duplicating color and brightness
arguments in every visual command.

### Brightness and color — `0x30..0x3F`

| Byte | Command | Arguments | Persistence |
|---:|---|---|---|
| `0x30` | `SET_GLOBAL_BRIGHTNESS` | `level` | Persisted |
| `0x31` | `SET_TEMP_BRIGHTNESS` | `level` | Volatile |
| `0x32` | `CLEAR_TEMP_BRIGHTNESS` | none | Volatile |
| `0x33` | `SET_GLOBAL_COLOR` | `R, G, B` | Persisted |
| `0x34` | `SET_TEMP_COLOR` | `R, G, B` | Volatile |
| `0x35` | `CLEAR_TEMP_COLOR` | none | Volatile |

Global settings take effect immediately and are written only when explicitly
changed by the user. Temporary settings take effect immediately without a
persistent-memory write. Clearing a temporary override reveals the current
global value.

### Development and maintenance — `0x70..0x7F`

| Byte | Command | Arguments |
|---:|---|---|
| `0x70` | `SHOW_RAW_FRAME_CHUNK` | `tag, frame_offset:u16, data:0..28 bytes` |
| `0x71` | `SHOW_RAW_FRAME_COMMIT` | `tag, frame_length:u16` |
| `0x72` | `IDENTIFY` | none |
| `0x73` | `EXIT_LOCAL_TEST` | none |
| `0x74` | `CLEAR_ERROR` | none |
| `0x75` | `SHOW_DEV_TEXT` | `tag, ASCII text:1..29 bytes` |
| `0x7F` | `FACTORY_RESET_SETTINGS` | confirmation bytes `0x22, 0xA5` |

Raw frames are for hardware validation, simulator preview, and development.
Normal operation should request stored semantic content. The module keeps a
temporary raw-frame buffer so a hardware-sized frame may exceed one packet.

`SHOW_DEV_TEXT` is a volatile Rev D development aid for button-driven mode and
test-selection feedback. It scrolls one centered line once and then clears the
display. It does not replace or persist the normal message buffer.

Factory reset restores safe brightness/color defaults and the message
`Please Insert Girder`. The two confirmation bytes reduce accidental resets;
the Brain UI should still require explicit user confirmation.

## Status readback

The Brain reads a fixed 20-byte status record directly from the module. No
selector write is conceptually required. If a CircuitPython target
implementation needs a preparatory request, it may temporarily use an internal
`PREPARE_STATUS` command without changing the contents below.

| Offset | Field | Size | Meaning |
|---:|---|---:|---|
| 0 | `magic` | 1 | `0x22` for a BU-22 module |
| 1 | `protocol_major` | 1 | `0` for this draft |
| 2 | `protocol_minor` | 1 | Initial value `2` for named local modes |
| 3 | `module_type` | 1 | `1=Eyes`, `2=Mouth` |
| 4 | `firmware_major` | 1 | Firmware version |
| 5 | `firmware_minor` | 1 | Firmware version |
| 6 | `lifecycle_state` | 1 | Lifecycle enumeration |
| 7 | `display_state` | 1 | Visual-state enumeration |
| 8 | `activity_state` | 1 | Activity enumeration |
| 9 | `active_tag` | 1 | Tag of current/latest visual request |
| 10 | `last_command` | 1 | Most recently accepted command byte |
| 11 | `error_code` | 1 | Current error enumeration |
| 12–13 | `active_content_id` | 2 | Expression/animation/performance identifier |
| 14 | `global_brightness` | 1 | Stored level |
| 15 | `effective_brightness` | 1 | Level currently applied |
| 16 | `flags` | 1 | Status flag bits |
| 17 | `i2c_address` | 1 | Active address |
| 18–19 | `feature_flags` | 2 | Supported optional features |

Status flags:

| Bit | Meaning |
|---:|---|
| 0 | Brain communication has been observed within timeout |
| 1 | Local `TEST` mode active |
| 2 | Temporary brightness override active |
| 3 | Temporary color override active |
| 4 | Timed activity busy |
| 5 | Most recent tagged activity completed normally |
| 6 | Local `BENDER` mode active |
| 7 | Persistent settings passed integrity validation |

The completion bit describes `active_tag`. A replacement command immediately
changes `active_tag` and clears completion. This prevents the Brain from
mistaking completion of an older activity for the current one.

### Development local modes

The Rev D controller button cycles three named local modes. They are derived
from lifecycle and status flags without changing the fixed 20-byte record:

| Name | Lifecycle | Status flags | Visual commands |
|---|---|---|---|
| `TARGET` | Waiting for Brain or Brain Controlled | Bits 1 and 6 clear | Accepted |
| `TEST` | Local Test | Bit 1 set | Rejected with error 10 |
| `BENDER` | Standalone Normal | Bit 6 set | Rejected with error 10 |

Identity and status reads remain available in every mode. Software APIs expose
`0=TARGET`, `1=TEST`, and `2=BENDER`; variable-length names are not placed in
the status packet.

## Enumerations

### Module type

| Value | Meaning |
|---:|---|
| 1 | Eyes |
| 2 | Mouth |

### Lifecycle state

| Value | Meaning |
|---:|---|
| 0 | Booting |
| 1 | Waiting for Brain |
| 2 | Standalone Normal |
| 3 | Brain Controlled |
| 4 | Local Test |
| 5 | Error |

### Display state

| Value | Meaning |
|---:|---|
| 0 | Normal |
| 1 | Static Expression |
| 2 | Animation |
| 3 | Performance |
| 4 | Clock |
| 5 | Message |
| 6 | Off |
| 7 | Raw Frame |
| 8 | Local Test |
| 9 | Error Display |

### Activity state

| Value | Meaning |
|---:|---|
| 0 | Idle/static |
| 1 | Running |
| 2 | Complete |
| 3 | Interrupted |
| 4 | Waiting for data/commit |

### Error code

| Value | Meaning |
|---:|---|
| 0 | No error |
| 1 | Unknown command |
| 2 | Incorrect packet length |
| 3 | Invalid argument |
| 4 | Unknown content identifier |
| 5 | Unsupported feature |
| 6 | Transfer incomplete or invalid |
| 7 | Persistent-settings integrity failure |
| 8 | Rendering/data failure |
| 9 | Hardware initialization failure |
| 10 | Busy in local `TEST` or `BENDER` mode |

An unknown content identifier enters the visible Error Display during
development. `active_content_id` contains the requested missing ID and
`last_command` identifies whether the failed request was an expression,
animation, or performance. The next valid visual command clears the visible
error and executes normally. A later production policy may choose a quieter
Normal fallback while preserving status.

## Content catalogs and compatibility

Expressions, animations, and performances use separate zero-based 16-bit ID
spaces. Human-readable names exist in source and simulator data; only the
numeric ID crosses I2C.

Before v1, catalogs are experimental and may be reset or reorganized while the
system is developed. At the v1 release, the reviewed IDs become stable. After
v1:

- Existing IDs are not renumbered, removed, or reused.
- New entries are appended.
- An existing entry may gain improved rendering or timing if its semantic
  meaning remains the same.
- A meaningfully different behavior receives a new ID, such as `BLINK_FAST`.

This allows Brain and display implementations to improve independently while a
request such as `PLAY_ANIMATION(BLINK)` retains its meaning.

## Feature flags

Feature bits allow Brain firmware to work with different display revisions.

| Bit | Capability |
|---:|---|
| 0 | Static expressions |
| 1 | Local animations |
| 2 | Local module performances |
| 3 | Clock renderer |
| 4 | Message renderer and persistent message |
| 5 | Visor renderer |
| 6 | RGB color control |
| 7 | Per-pixel brightness/raw frame |
| 8 | Local test button |
| 9 | Persistent settings |
| 10–15 | Reserved |

Eyes and Mouth may report different feature sets while using the same core
status layout and common commands.

## Command acceptance and interruption

- A well-formed visual command is acknowledged at the I2C transport level and
  becomes visible through `last_command`, `active_tag`, and status.
- Every new visual command immediately cancels the previous visual activity.
- No queued commands are retained by the display.
- Settings commands do not interrupt visual activity unless applying the new
  value inherently changes its appearance.
- Message upload commands do not display partial text.
- A valid Brain visual command immediately exits Local Test.
- Unknown or malformed commands do not replace the current valid display.

## Animation and performance data inside the module

The wire protocol selects stored content; it does not stream its timing steps.
A locally stored performance is conceptually:

```text
performance_id: angry_reaction
steps:
  normal       300 ms
  angry_1      500 ms
  angry_2     2000 ms
  angry_1      300 ms
  normal
```

The final storage format may be CircuitPython data, generated binary data, or a
compiled lookup table. It is independent of this wire protocol.

Animations and module performances return to Normal when complete. Visor Down
and Visor Up are dedicated global renderer transitions, not entries in the
animation catalog. Visor Down blanks complete rows top-to-bottom and finishes
Off. Visor Up reveals Normal rows bottom-to-top and finishes Normal.

## Startup and recovery

1. Module boots with LEDs black.
2. Module loads and validates persistent settings.
3. Module enters Waiting for Brain for approximately five seconds.
4. If no valid Brain transaction arrives, it enters Standalone Normal.
5. It continues listening indefinitely.
6. The first valid Brain visual command enters Brain Controlled and executes.
7. If communication later disappears, timed activity is cancelled and the
   module returns to Standalone Normal after the timeout.

The Brain periodically polls status while connected. On a missing target or
I2C error, it continues running, rescans, and reinitializes the returned module
with global settings followed by the desired visual state.

## CircuitPython v0 implementation note

Breadboard validation showed that the current CircuitPython I2C target loop
needs approximately 20 ms between immediately consecutive Brain transactions
so the target can return to listening. This is an implementation pacing value,
not part of the permanent semantic contract. The Brain v0 transport helper
should apply the delay centrally and future firmware/hardware can retest and
reduce it.

At 100 kHz, the tested 25-byte frame packets sustained 10 FPS with no late
frames. Production operation is expected to use stored expressions and local
timelines rather than continuous frame streaming.

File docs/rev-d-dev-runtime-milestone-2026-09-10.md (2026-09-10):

# Rev D development-runtime milestone

Date: 2026-09-10

The complete BU-22 V2 development hardware stack has passed its first stable,
button-driven runtime test:

- Brain perfboard discovered Eyes `0x30`, Mouth `0x31`, VCNL4200 `0x51`, and
  DS3231 `0x68` together and exchanged valid status and display commands.
- Both Rev D display controllers drove their complete development arrays from
  the validated 4 MHz SPI1 path: Eyes `18 x 16` (288 LEDs) and Mouth `15 x 11`
  (165 LEDs).
- Controller TARGET, TEST, and BENDER modes passed, including mode labels,
  line sweeps, module-local serpentine chase, solid colors, and static Bender
  artwork.
- Brain CLOCK, SETTINGS, BENDER, PLAY placeholder, and nested TEST modes run
  from physical buttons without requiring terminal commands.
- The temporary centered 3x5 font, three-second scrolling mode announcements,
  and fixed-position flashing clock colon were exercised on the development
  stack. Persistent settings, UTC RTC storage, North American time zones,
  manual DST, and 12/24-hour display are now implemented for the next detailed
  settings pass.
- Bench-verified Brain button mapping is `D5=MODE`, `D9=ENTER`, `D6=UP`, and
  `D10=DOWN`.

Logging and semantic I2C mirroring are present but disabled by default. The
firmware continues to answer status requests in local display modes and reports
named TARGET, TEST, or BENDER state through the fixed protocol status record.

## Next integration milestone

The next milestone is simulator-to-hardware animation delivery at the planned
10 FPS. Add a simulator development-board target matching the proven `18 x 16`
Eyes and `15 x 11` Mouth geometry while retaining the production-layout target.
Start with independently exported, loopable stored animations:

1. Eyes normal-to-angry-to-normal loop.
2. Mouth talking loop covering the chosen openness shapes.
3. A short combined performance referencing those stored animation IDs before
   adding synchronized audio.

This order validates geometry, pixel mapping, file representation, storage,
content identifiers, and loop timing before audio synchronization adds another
variable.

## Known development limitation

Powering all three RP2040 boards through one USB hub can backfeed or cause macOS
to remount every CIRCUITPY filesystem read-only. A host reboot or full hub power
cycle may be required before deployment. This is a hardware-development issue,
not an animation-protocol failure.

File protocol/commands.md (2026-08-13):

# BU-22 display protocol — raw validation experiment

This is a deliberately temporary, minimal protocol used to verify the physical
I2C connection and CircuitPython target support.

The feature-oriented semantic draft is maintained separately in
`semantic_protocol_v0.md`. Values in this file must not be treated as final
production command assignments.

## Addresses

| Module | Address |
|---|---:|
| Eyes | `0x30` |
| Mouth (reserved) | `0x31` |

## Brain-to-Eyes commands

Every transaction contains exactly one byte.

| Value | Name | Meaning |
|---:|---|---|
| `0x00` | `CLEAR` | Immediately display black on every eye LED |
| `0x01` | `IDENTIFY` | Briefly illuminate every eye channel amber |

There are no responses, parameters, status registers, retries, or checksums in
this first experiment. Those should be designed only after this basic path is
confirmed on the real hardware.

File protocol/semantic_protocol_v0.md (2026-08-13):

# BU-22 display protocol — semantic draft v0

This document defines what the Brain may ask a display module to do. It does
not assign command bytes or prescribe the final binary packet format.

The first corresponding binary encoding is documented in
`wire_protocol_v0.md`.

The raw breadboard commands in `commands.md` remain a separate hardware test
protocol.

## Ownership

- The Brain owns Bender's operating mode, orchestration, sensors, user input,
  RTC, audio timing, and coordination between Eyes, Mouth, and Antenna.
- Each display module owns its pixels, rendering, stored expressions, stored
  animations, locally accurate timing, persistent display settings, and local
  diagnostic button.
- Display modules do not autonomously schedule idle animations.
- A valid Brain display command immediately exits local test mode.

## Terms

### Display state

A persistent visual state that remains until replaced:

- Normal
- Static expression
- Clock
- Message
- Off
- Local test

### Expression

A named, static arrangement of pixels with no timing information.

Examples: `normal`, `angry_1`, `angry_2`, `bored`, `look_left`, `closed`.

### Animation

A finite, locally stored sequence of display states and durations. Animations
normally return to Normal.

Visor movement is a dedicated global display transition rather than cataloged
animation content. Visor Down interrupts all activity, turns off complete pixel
rows sequentially from top to bottom, and finishes Off. Visor Up starts black,
reveals Normal rows from bottom to top, and finishes Normal.

### Module performance

A longer, finite, locally stored timeline of expressions or display states and
durations. A module performance normally returns to Normal. It contains only
the activity for that module; the Brain coordinates the complete Bender
performance across modules and audio.

## Brain-to-display actions

### Core control

| Action | Arguments | Result |
|---|---|---|
| `SHOW_NORMAL` | none | Interrupt activity and show the module's Normal state |
| `SHOW_EXPRESSION` | expression identifier | Interrupt activity and hold the selected static expression |
| `PLAY_ANIMATION` | animation identifier | Interrupt activity and play a locally stored finite animation |
| `PLAY_PERFORMANCE` | performance identifier | Interrupt activity and play a locally stored finite module performance |
| `STOP` | none | Interrupt activity and show Normal |
| `SET_OFF` | none | Interrupt activity, render black, and remain Off |
| `PLAY_VISOR_DOWN` | optional speed | Animate the eye visor downward and finish Off |
| `PLAY_VISOR_UP` | optional speed | Animate the eye visor upward and finish Normal |

### Clock and message

| Action | Arguments | Result |
|---|---|---|
| `SHOW_CLOCK` | hour, minute, colon mode, optional color | Interrupt activity and continuously show the supplied time |
| `UPDATE_CLOCK` | hour, minute | Update an already active clock without restarting its renderer |
| `SHOW_MESSAGE` | optional temporary brightness/color | Interrupt activity and scroll the stored message repeatedly |
| `SET_MESSAGE` | UTF-8/ASCII text, maximum 128 characters | Replace and persist the module's stored message |
| `RESET_MESSAGE` | none | Restore and persist `Please Insert Girder` |

The Brain owns actual timekeeping. Eyes owns font rendering, scrolling, and
local colon blinking after receiving the current time and colon mode.

### Brightness and color

| Action | Arguments | Persistence |
|---|---|---|
| `SET_GLOBAL_BRIGHTNESS` | level | Persisted user preference |
| `SET_TEMP_BRIGHTNESS` | level | Volatile override |
| `CLEAR_TEMP_BRIGHTNESS` | none | Restore stored global brightness |
| `SET_GLOBAL_COLOR` | color | Persisted user preference |
| `SET_TEMP_COLOR` | color | Volatile override |
| `CLEAR_TEMP_COLOR` | none | Restore stored global color |

Temporary overrides exist for a mode, performance, ambient-light response, or
special effect. They never write persistent memory. Effective brightness and
color use the temporary values while present and otherwise use global values.

Persistent writes should occur only when a user explicitly changes a saved
setting, not for every ambient-light adjustment.

### Development and maintenance

| Action | Arguments | Result |
|---|---|---|
| `SHOW_RAW_FRAME` | hardware-sized frame | Render one development/simulator frame |
| `IDENTIFY` | none | Run a brief, recognizable module identification display |
| `EXIT_LOCAL_TEST` | none | Leave diagnostics and show Normal |
| `FACTORY_RESET_SETTINGS` | guarded confirmation | Restore default brightness, color, and message |

Raw frames are a development feature. Normal Brain operation should request
semantic content stored and rendered by the module.

## Display-to-Brain information

The Brain polls display modules. A module does not initiate I2C transactions.

### Identity

- Module type: Eyes or Mouth
- Hardware compatibility identifier
- Firmware version
- Supported feature flags
- Configured I2C address

### Runtime status

- Lifecycle state
- Visual/display state
- Active expression, animation, or performance identifier
- Busy or complete
- Last accepted command
- Brain communication present/lost
- Local test active
- Temporary brightness/color override active

### Error status

- No error
- Unknown action
- Invalid argument or identifier
- Unsupported feature
- Malformed or incomplete transfer
- Persistent-settings integrity failure
- Rendering/data failure
- Hardware initialization failure

Errors remain queryable until cleared by an explicit action or a successful
replacement operation, depending on error type.

## Lifecycle states

Display modules distinguish these internal lifecycle states:

1. `BOOTING`
2. `WAITING_FOR_BRAIN`
3. `STANDALONE_NORMAL`
4. `BRAIN_CONTROLLED`
5. `LOCAL_TEST`
6. `ERROR`

On power-up, outputs remain black while hardware initializes and persisted
settings load. The module waits approximately five seconds for valid Brain
communication. If none arrives, Eyes shows Normal eyes and Mouth shows its
normal resting state. Both continue listening indefinitely.

If communication is lost after connection, the module cancels local timed
activity and enters Standalone Normal after the same timeout. The first valid
Brain display command immediately restores Brain Controlled operation.

## Interruption and completion rules

- A new visual command immediately replaces the current visual activity.
- `STOP`, `SHOW_NORMAL`, and `SET_OFF` always take effect immediately.
- There is no command queue inside a display module.
- An interrupted activity does not resume automatically.
- Animations and module performances normally finish at Normal.
- Visor Down finishes Off; Visor Up finishes Normal.
- A completed module reports completion and its resulting state.
- The Brain decides the next whole-system action. For example, after an angry
  eye performance completes at Normal, the Brain may request Clock.

## Local test button

The display-controller button cycles through local diagnostics such as:

- Normal
- Stored expression/animation demonstration
- Channel test
- Pixel-order test
- Color test
- Brightness ramp
- I2C connection status
- I2C address
- Last command
- Error indication

Any valid Brain display command immediately exits Local Test and is executed.
Local Test never prevents the Brain from regaining control.

## Persistent defaults

- Stored message: `Please Insert Girder`
- Global brightness: conservative mid-level value, finalized after hardware testing
- Global color: Bender eye amber, finalized after diffuser testing
- Temporary overrides: none

Persistent data should include a format version and integrity check. Invalid
data loads safe defaults and sets a queryable settings-integrity error.

## Brain orchestration examples

### Expression followed by clock

1. Brain requests `PLAY_PERFORMANCE(angry_reaction)`.
2. Eyes plays its locally timed sequence and finishes Normal.
3. Brain observes completion or reaches the coordinated timeline point.
4. Brain requests `SHOW_CLOCK(...)`.

### Sensor/user interruption

1. Eyes is playing a performance.
2. User changes mode, presses mute, or leaves the sensor area.
3. Brain immediately requests `STOP`, `SET_OFF`, or another display state.
4. Eyes abandons the previous activity and executes the replacement.

### Ambient brightness

1. Brain reads the ambient-light sensor.
2. Brain requests `SET_TEMP_BRIGHTNESS(level)`.
3. Eyes applies it without persistent writes.
4. Brain requests `CLEAR_TEMP_BRIGHTNESS` when the override is no longer needed.

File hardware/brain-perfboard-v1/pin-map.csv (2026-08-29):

Function | Net | Feather label | RP2040 GPIO | Direction | Notes
I2C data | SDA | SDA | GP2 | Bidirectional | Feather Qwiic bus
I2C clock | SCL | SCL | GP3 | Output | Feather Qwiic bus
Audio transmit | AUDIO_RX | TX | GP0 | Output | Connect to Audio FX RX
Audio receive | AUDIO_TX | RX | GP1 | Input | Connect to Audio FX TX
Audio activity | AUDIO_ACT | D24 | GP24 | Input | Audio FX ACT is active low
Audio reset | AUDIO_RST | D25 | GP25 | Open-drain style output | Drive low then release
RTC heartbeat | HEARTBEAT | D13 | GP13 | Input | DS3231 SQW open drain; optional 10k pull-up
Motion/sensor | SENSOR | A3 | GP29 | Input/ADC | Sensor dependent
Antenna red | ANT_R | A0 | GP26 | PWM output | Use external current limiting/driver as needed
Antenna green | ANT_G | A1 | GP27 | PWM output | Use external current limiting/driver as needed
Antenna blue/spare | ANT_B | A2 | GP28 | PWM output | May remain spare
Button 1 | BTN1 | D4 | GP6 | Input pull-up | Shared button ground
Button 2 | BTN2 | D5 | GP7 | Input pull-up | Shared button ground
Button 3 | BTN3 | D6 | GP8 | Input pull-up | Shared button ground
Button 4 | BTN4 | D9 | GP9 | Input pull-up | Shared button ground
Button 5 | BTN5 | D10 | GP10 | Input pull-up | Shared button ground
Button 6 | BTN6 | D11 | GP11 | Input pull-up | Shared button ground
Button 7 | BTN7 | D12 | GP12 | Input pull-up | Shared button ground
Spare SPI clock | SPARE_SCK | SCK | GP18 | Bidirectional | Broken out
Spare SPI data out | SPARE_MO | MO | GP19 | Bidirectional | Broken out
Spare SPI data in | SPARE_MI | MI | GP20 | Bidirectional | Broken out

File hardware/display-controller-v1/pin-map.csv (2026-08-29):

Net | KB2040 label | RP2040 GPIO | Buffer | Output
CH1_DATA | D2 | GP2 | U1A | J1 pin 3
CH1_CLOCK | D3 | GP3 | U1B | J1 pin 4
CH2_DATA | D4 | GP4 | U1C | J2 pin 3
CH2_CLOCK | D5 | GP5 | U1D | J2 pin 4
CH3_DATA | D6 | GP6 | U2A | J3 pin 3
CH3_CLOCK | D7 | GP7 | U2B | J3 pin 4
CH4_DATA | D8 | GP8 | U2C | J4 pin 3
CH4_CLOCK | D9 | GP9 | U2D | J4 pin 4
CH5_DATA | SCK | GP18 | U3A | J5 pin 3
CH5_CLOCK | A0 | GP26 | U3B | J5 pin 4
CH6_DATA | A1 | GP27 | U3C | J6 pin 3
CH6_CLOCK | A2 | GP28 | U3D | J6 pin 4
I2C_SDA | TX | GP0 |  | I2C IN/THRU
I2C_SCL | RX | GP1 |  | I2C IN/THRU
ADDRESS | A3 | GP29 |  | JP1 resistor-coded 2x2 header
HEARTBEAT | D10 | GP10 |  | J11 pin 2
TEST | MISO | GP20 |  | SW1 / J11 pin 3
BUFFER_ENABLE | MOSI | GP19 |  | Q1 base network
RESET | RST |  |  | SW2 / J11 pin 4

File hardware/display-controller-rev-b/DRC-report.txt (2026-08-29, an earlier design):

** Drc report for BU-22-Display-Controller-Rev-B.kicad_pcb **
** Created on 2026-08-16T13:03:59 **
** Report includes: Errors, Warnings, Exclusions **

** Found 15 DRC violations **
[courtyards_overlap]: Courtyards overlap
    Rule: board setup constraints courtyard; error
    @(108.0000 mm, 36.0000 mm): Footprint D1
    @(112.0000 mm, 39.0000 mm): Footprint R19
[courtyards_overlap]: Courtyards overlap
    Rule: board setup constraints courtyard; error
    @(119.0000 mm, 20.0000 mm): Footprint J7
    @(113.5000 mm, 14.0000 mm): Footprint R12
[text_height]: Text height out of range (board setup constraints silk text height min height 0.8000 mm; actual 0.6500 mm)
    Rule: board setup constraints silk text height; warning
    @(36.5000 mm, 48.0000 mm): PCB text 'EYES' on F.Silkscreen
[text_height]: Text height out of range (board setup constraints silk text height min height 0.8000 mm; actual 0.6500 mm)
    Rule: board setup constraints silk text height; warning
    @(51.5000 mm, 48.0000 mm): PCB text 'MOUTH' on F.Silkscreen
[text_height]: Text height out of range (board setup constraints silk text height min height 0.8000 mm; actual 0.7000 mm)
    Rule: board setup constraints silk text height; warning
    @(15.0000 mm, 41.0000 mm): PCB text 'I2C' on F.Silkscreen
[text_height]: Text height out of range (board setup constraints silk text height min height 0.8000 mm; actual 0.7000 mm)
    Rule: board setup constraints silk text height; warning
    @(22.5000 mm, 16.8000 mm): PCB text 'U1' on F.Silkscreen
[text_height]: Text height out of range (board setup constraints silk text height min height 0.8000 mm; actual 0.7000 mm)
    Rule: board setup constraints silk text height; warning
    @(38.0000 mm, 41.0000 mm): PCB text 'HB' on F.Silkscreen
[text_height]: Text height out of range (board setup constraints silk text height min height 0.8000 mm; actual 0.7000 mm)
    Rule: board setup constraints silk text height; warning
    @(60.5000 mm, 16.8000 mm): PCB text 'U2' on F.Silkscreen
[text_height]: Text height out of range (board setup constraints silk text height min height 0.8000 mm; actual 0.7000 mm)
    Rule: board setup constraints silk text height; warning
    @(98.5000 mm, 16.8000 mm): PCB text 'U3' on F.Silkscreen
[silk_overlap]: Silkscreen clearance
    Rule: board setup constraints silk; warning
    @(38.2650 mm, 41.2271 mm): Segment of R16 on F.Silkscreen
    @(38.0000 mm, 41.0000 mm): PCB text 'HB' on F.Silkscreen
[silk_overlap]: Silkscreen clearance
    Rule: board setup constraints silk; warning
    @(113.6800 mm, 22.6600 mm): Segment of J7 on F.Silkscreen
    @(111.5000 mm, 22.7000 mm): PCB text '- GND' on F.Silkscreen
[silk_overlap]: Silkscreen clearance
    Rule: board setup constraints silk; warning
    @(123.7200 mm, 22.6600 mm): Segment of J7 on F.Silkscreen
    @(111.5000 mm, 22.7000 mm): PCB text '- GND' on F.Silkscreen
[silk_over_copper]: Silkscreen clipped by solder mask
    Local override; warning
    @(38.0000 mm, 41.0000 mm): PCB text 'HB' on F.Silkscreen
    @(39.0000 mm, 40.0875 mm): Pad 2 [ADDRESS] of R16 on F.Cu
[silk_over_copper]: Silkscreen clipped by solder mask
    Local override; warning
    @(113.6800 mm, 22.6600 mm): Segment of J7 on F.Silkscreen
    @(113.5000 mm, 14.9125 mm): Pad 1 [CH6_CLOCK_5V] of R12 on F.Cu
[silk_over_copper]: Silkscreen clipped by solder mask
    Local override; warning
    @(113.6800 mm, 22.6600 mm): Segment of J7 on F.Silkscreen
    @(113.5000 mm, 13.0875 mm): Pad 2 [CH6_CLOCK_OUT] of R12 on F.Cu

** Found 0 unconnected pads **

** Found 0 Footprint errors **

** Ignored checks **
    - Footprint has no courtyard defined
    - Track endpoint not centered on via
    - Tuning profile track geometries
    - Footprint doesn't match symbol's footprint filters
    - Footprint component type doesn't match footprint pads

** End of Report **

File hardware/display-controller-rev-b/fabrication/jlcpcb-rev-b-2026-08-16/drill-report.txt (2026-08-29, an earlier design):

Drill report for BU-22-Display-Controller-Rev-B.kicad_pcb
Created on 2026-08-16T14:43:49

Copper Layer Stackup:
    =============================================================
    L1 :  F.Cu                      front
    L2 :  In1.Cu                    in1
    L3 :  In2.Cu                    in2
    L4 :  B.Cu                      back

Drill file 'BU-22-Display-Controller-Rev-B-PTH.drl' contains
    plated through holes:
    =============================================================
    T1  0.300mm  0.0118"  (29 holes))
    T2  0.750mm  0.0295"  (9 holes))
    T3  0.800mm  0.0315"  (2 holes))
    T4  0.900mm  0.0354"  (4 holes))
    T5  0.950mm  0.0374"  (24 holes))
    T6  1.000mm  0.0394"  (32 holes))
    T7  1.100mm  0.0433"  (8 holes))
    T8  1.300mm  0.0512"  (2 holes))

    Total plated holes count 110

Drill file 'BU-22-Display-Controller-Rev-B-NPTH.drl' contains
    unplated through holes:
    =============================================================
    T1  3.200mm  0.1260"  (4 holes))

    Total unplated holes count 4

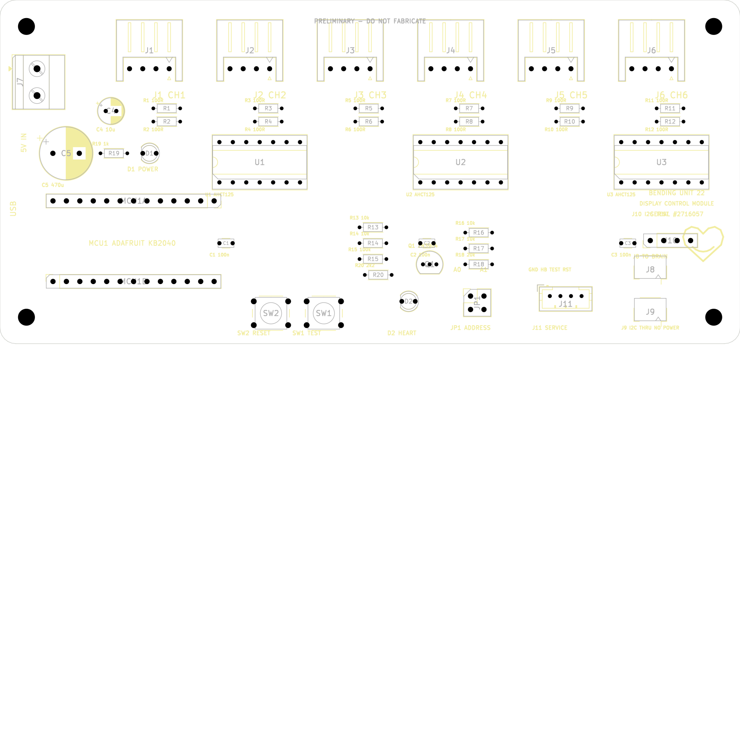
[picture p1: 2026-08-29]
hardware/display-controller-v1/placement-preview.png

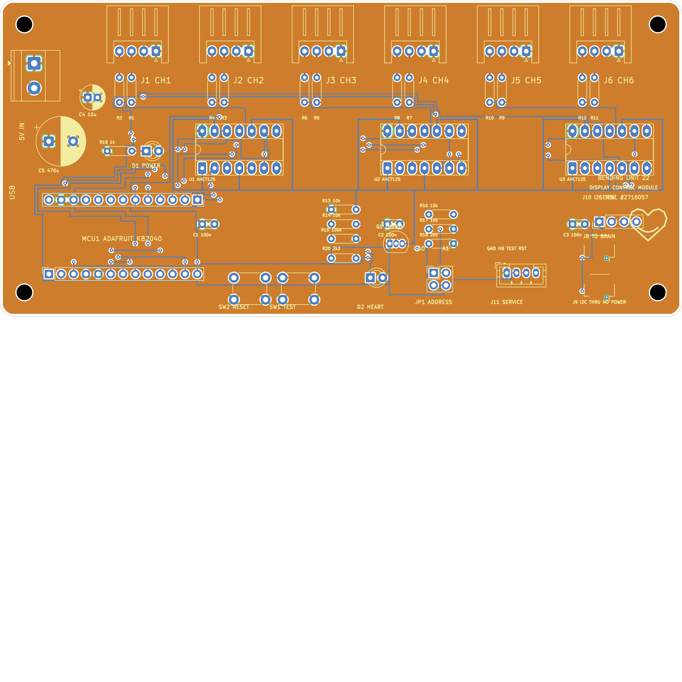
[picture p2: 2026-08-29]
hardware/display-controller-v1/routing-preview.png

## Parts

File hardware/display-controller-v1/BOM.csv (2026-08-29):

Reference | Quantity | Value | Package | Assembly note
U1-U3 | 3 | SN74AHCT125N | DIP-14 | Use sockets
MCU1 | 1 | Adafruit KB2040 | 2x 1x13 socket headers | Socketed with USB exposed at edge
J1-J6 | 6 | JST-XH 4-pin 2.50mm | B4B-XH-A or S4B-XH-A | Vertical or right-angle
J7 | 1 | 5V input | 2-pin 5.08mm screw terminal | Measure purchased part before order
J8-J9 | 2 | Qwiic JST-SH 4-pin | SMT horizontal | Only intentional SMT parts
J10 | 1 | I2C test | 1x4 2.54mm pin header | All four Brain cable conductors exposed
J11 | 1 | Service IO JST-PH | 4-pin 2.00mm vertical | GND heartbeat TEST and RESET
JP1 | 1 | Four-state address | 2x2 2.54mm header | Two removable shunts select four addresses
SW1 | 1 | TEST | 6mm tactile switch | Through-hole
SW2 | 1 | RESET | 6mm tactile switch | Through-hole
Q1 | 1 | 2N3904 E-B-C | TO-92 inline | Verify purchased transistor lead order before soldering
R1-R12 | 12 | 100 ohm | Axial DIN0204 | Output source termination
R13 | 1 | 10k | Axial DIN0204 | OE_N 5V pull-up
R14 | 1 | 10k | Axial DIN0204 | OE transistor base resistor
R15 | 1 | 100k | Axial DIN0204 | OE GPIO pull-down
R16 | 1 | 10k | Axial DIN0204 | Address ADC pull-up to local 3V3
R17 | 1 | 10k | Axial DIN0204 | Address shunt A0 resistor
R18 | 1 | 20k | Axial DIN0204 | Address shunt A1 resistor
R19 | 1 | 1k | Axial DIN0204 | Green power LED
R20 | 1 | 2.2k | Axial DIN0204 | Red heartbeat LED low-current drive
C1-C3 | 3 | 100nF | Leaded ceramic 2.50mm | One per AHCT125
C4 | 1 | 10uF 10V or greater | Radial electrolytic | Controller local bulk
C5 | 1 | 470uF 10V or greater | Radial electrolytic | Display power input bulk
D1 | 1 | Green LED | 3mm through-hole | Power status
D2 | 1 | Red LED | 3mm through-hole | Heartbeat status driven directly at low current
H1-H4 | 4 | M3 mounting hole | 3.2mm plated-free hole | 5mm from corners

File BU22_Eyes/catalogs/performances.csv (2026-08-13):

id | name | description
0 | WAKE_UP | Wake-up eye performance
1 | ANGRY_REACTION | Build to angry and return to Normal
2 | SUSPICIOUS_LOOK | Suspicious eye reaction and return to Normal

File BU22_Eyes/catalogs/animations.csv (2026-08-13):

id | name | description
0 | BLINK | One normal blink
1 | DOUBLE_BLINK | Two quick blinks
2 | WINK_LEFT | Left eye wink relative to observer
3 | WINK_RIGHT | Right eye wink relative to observer
4 | LOOK_LEFT | Look left and return to Normal
5 | LOOK_RIGHT | Look right and return to Normal

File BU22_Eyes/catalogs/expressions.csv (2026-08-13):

id | name | description
0 | NORMAL | Normal open Bender eyes
1 | CLOSED | Both eyes closed
2 | LOOK_LEFT | Pupils looking left relative to observer
3 | LOOK_RIGHT | Pupils looking right relative to observer
4 | ANGRY_1 | Partially angry eyelids
5 | ANGRY_2 | Fully angry eyelids
6 | BORED | Bored upper eyelids
7 | WORRIED | Worried lower eyelids

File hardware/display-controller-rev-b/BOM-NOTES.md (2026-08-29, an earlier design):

# BU-22 Display Controller Rev B BOM notes

The CSV in this directory is the purchasing BOM for the approved Rev B board.
It lists quantities per controller, quantities for two controllers, and a
practical recommended purchase quantity including inexpensive spares.

## Critical substitutions

- U1-U3 must be **74AHCT125** devices in the 3.9 mm SOIC-14 package. AHCT is
  important because the buffers run at 5 V while accepting 3.3 V RP2040 logic.
  Do not substitute a 74HC125 without rechecking its input-high threshold.
- Q1 must have the TO-92 lead order **E-B-C on pins 1-2-3**. The PCB connects
  pad 1 to ground, pad 2 to the base resistor, and pad 3 to the common OE line.
- J8 and J9 are the 1.0 mm JST-SH top-entry footprint commonly used for Qwiic.
  They are small SMD parts and will be the most delicate hand-soldering job.
- The KB2040 requires two 1x13 female 2.54 mm socket rows. Do not solder the
  module directly to the controller board.

## User-supplied parts

- Adafruit KB2040 module
- 5.08 mm power screw terminal
- Six `B4B-XH-A` channel headers per board; 24 are already owned

## Suggested build order

1. Solder all 0805 resistors and capacitors.
2. Solder U1-U3 and the two Qwiic headers.
3. Check for 5 V/GND shorts before adding through-hole parts.
4. Add Q1, LEDs, switches, electrolytic capacitors and connectors.
5. Install the female KB2040 socket rows last, using the module to hold their
   alignment while soldering only if the entire board is unpowered.

## Quantities

The recommended quantities target two assembled display controllers with
spares. For a single controller, use the `Qty per board` column directly.

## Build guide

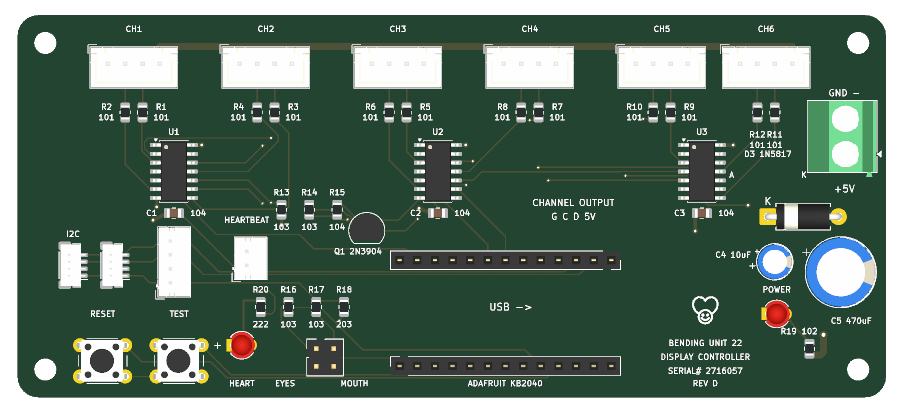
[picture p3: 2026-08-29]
hardware/display-controller-rev-d/fabrication/BU-22-Display-Controller-Rev-D-preview.png

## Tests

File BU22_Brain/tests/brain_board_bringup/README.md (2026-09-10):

# BU-22 Brain board bring-up

Interactive CircuitPython test for the Feather RP2040 Brain perfboard V1.

The automatic startup sequence is intentionally non-destructive:

1. Scan and identify the I2C bus.
2. Read the DS3231 RTC when present.
3. Report all seven buttons, Audio FX ACT, and sensor/interrupt inputs.
4. Configure the RTC SQW output for 1 Hz and measure it for 4.5 seconds.
5. Leave antenna outputs low and Audio FX reset released.

The Feather NeoPixel is amber during startup and then turns off. The external
heartbeat LED provides the visible 1 Hz indication without lighting the
onboard NeoPixel continuously.

Use the USB serial console for output tests:

| Key | Test |
|---|---|
| `s` | Scan I2C |
| `r` | Read RTC |
| `t YYYY-MM-DD HH:MM:SS` | Set RTC from a local wall-clock value |
| `h` | Measure SQW heartbeat |
| `i` | Print input states |
| `v` | Stream VCNL4200 proximity, white-light, lux, and interrupt readings |
| `f` | Read and clear latched VCNL4200 interrupt flags |
| `a COLOR` | Hold only the requested red, green, or blue output high for 3 seconds |
| `l` | Request the Audio FX track list without playing audio |
| `p NUMBER` | Play `Txx.WAV`; for example, `p 3` plays `T03.WAV` |
| `x` | Pulse the Audio FX reset line |
| `e normal`, `e angry`, `e off` | Select the static Eyes image |
| `m normal`, `m open`, `m off` | Select the static Mouth image |
| `q eyes`, `q mouth` | Read the controller's 20-byte protocol status |
| `g` | Start or stop the repeating eight-second, 10 FPS Eyes/Mouth performance |
| `?` | Print help |

The `t` command stores the supplied fields exactly as entered. It performs no
timezone or daylight-saving conversion. Audio playback is explicit because it
drives the attached speakers. Track numbers from 0 through 99 map directly to
the corresponding two-digit filename, `T00.WAV` through `T99.WAV`.

Each button press/release is printed automatically. The onboard NeoPixel is
amber during startup and then remains off.

The antenna command accepts full names or first letters, such as `a red` or
`a r`. It holds all unrequested antenna outputs low, drives the requested 3.3 V
GPIO high for three seconds, and then returns it low. Use an appropriate
resistor or transistor driver for the physical antenna load.

Commands that take an argument (`a`, `p`, and `t`) wait up to ten seconds for
the remainder of the line so they can be typed interactively.

The `v` sensor monitor prints readings about five times per second and stops
when any serial-console key is pressed. Move a hand toward and away from the
sensor while watching raw `proximity` and `white` values. `lux` is the driver's
calculated ambient-light value; `INT` is the level observed on A3. The monitor
configures an active-low, close-only proximity interrupt with a threshold of
10 and two-reading persistence. It clears prior interrupt flags when the
monitor starts. Close-only mode is intentional while INT is tested directly
and remains disconnected from A3; it prevents the idle reading below 5 from
immediately latching an away event. When A3 is later connected and low, the
monitor reads and prints the sensor interrupt flags, clearing the event.
While INT remains disconnected from A3, stop the monitor, move away from the
sensor, and use `f` to acknowledge a latched close event. The physical INT pin
should then return high.

## Install

With the Feather mounted as `CIRCUITPY`, run from this directory:

```sh
python3 -m circup install -r requirements.txt
cp code.py config.py /Volumes/CIRCUITPY/
```

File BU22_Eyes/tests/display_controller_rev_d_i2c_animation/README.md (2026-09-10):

# Stored-frame I2C animation test

This integrated test receives tagged `SHOW_EXPRESSION` commands from the Brain
at 10 FPS and renders stored frames locally over the combined CH5-clock/CH6-data
hardware-SPI1 output at 4 MHz.

- Eyes supports content IDs 0 center, 2 left, and 3 right across two 9x16
  panels.
- Mouth supports content IDs 0 through 4 from closed to fully open across three
  5x11 tiles.

The Brain sends the same frame tag to both controllers. This is a temporary
hardware/protocol validation; it does not finalize the simulator export format.

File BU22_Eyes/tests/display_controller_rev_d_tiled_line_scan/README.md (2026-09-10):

# Tiled horizontal and vertical line scan

This 10 FPS diagnostic verifies logical coordinate mapping across daisy-chained
column-serpentine modules. Each module restarts at its own top-left pixel, so a
logical line remains continuous when the physical chain jumps from the end of
one module to the beginning of the next.

- Eyes: two 9x16 modules form an 18x16 display.
- Mouth: three 5x11 modules form a 15x11 display.
- Cyan horizontal line scans top-to-bottom.
- Purple vertical line scans left-to-right.

Output uses hardware SPI1: CH5 `CLOCK` (`A0`) and CH6 `DATA` (`A1`) at 4 MHz.

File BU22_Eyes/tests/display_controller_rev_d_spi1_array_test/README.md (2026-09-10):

# Combined CH5/CH6 SPI1 full-array test

This test validates a complete daisy-chained array using hardware SPI1. Take
clock from CH5 `CLOCK` (`A0`) and data from CH6 `DATA` (`A1`), with common
ground and external 5 V power. Leave CH5 data and CH6 clock disconnected.

- `eye_config.py`: two 9x16 panels, 288 LEDs total.
- `mouth_config.py`: three 5x11 tiles, 165 LEDs total.

The repeating sequence is a complete single-pixel chase, solid red, solid
green, solid blue, dim white, and black.

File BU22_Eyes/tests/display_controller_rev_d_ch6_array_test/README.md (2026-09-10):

# CH6 full-array LED test

This test validates every LED in a daisy-chained half-scale BU-22 array using
the controller's conventional CH6 output (`A2` clock and `A1` data). It runs a
single-pixel chase followed by solid red, green, blue, dim white, and black.

- `eye_config.py`: two 9x16 panels, 288 LEDs total.
- `mouth_config.py`: three 5x11 tiles, 165 LEDs total.

Copy `code.py` and the appropriate configuration as `config.py` to the target
controller. Use an external 5 V LED supply with common ground; USB is for
programming and serial only.

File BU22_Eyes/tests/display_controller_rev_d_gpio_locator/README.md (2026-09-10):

# Rev D GPIO-to-output locator

This meter-friendly diagnostic empirically maps the KB2040 `D2` through `D9`
GPIO names to the physical CH1 through CH4 output pins. It makes no assumption
about the MCU1B socket pad orientation. Only one candidate GPIO is high at a
time; all other candidates remain low.

Disconnect LED arrays. Probe one connector signal pin, watch the visible serial
terminal, and record which named GPIO causes that physical pin to go high.

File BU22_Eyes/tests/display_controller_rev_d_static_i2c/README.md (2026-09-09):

# Rev D half-scale static Eyes I2C test

Protocol-capable static test for two `9 x 16` serpentine eye tiles. The physical
left eye is on CH6 and the physical right eye is on CH5. Both use the same
symmetric `8 x 16` image starting at their tile's leftmost column; each tile's
ninth/rightmost column is unused. The first and last rows remain dark so the
temporary tiles appear less vertically open. Each pupil is two dark columns by
four rows. It displays Normal; Brain commands
select Normal, Angry, or Off. It uses the existing
`SHOW_NORMAL`, `SHOW_EXPRESSION`, and `SET_OFF` protocol operations and returns
the proven 20-byte status structure.

The Rev D A3 jumper network still selects the target address at startup. This
board should be jumpered as Eyes and report `0x30`.

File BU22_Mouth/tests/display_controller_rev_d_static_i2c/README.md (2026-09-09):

# Rev D half-scale static Mouth I2C test

Protocol-capable static test treating three `5 x 11` serpentine mouth tiles as
one `15 x 11` display. CH6 renders the left tile and CH5 the center tile. For
diagnosis, the rightmost tile pattern is duplicated on CH1 through CH4 so the
same physical tile can test any of those connectors. On startup it displays
Normal; Brain commands select Normal,
Open, or Off. The logical grid repeats three lit rows or columns followed by
one dark separator across the complete display; physical tile boundaries do
not define the grid. Open bows the two dark horizontal lines away from each
other near the center.

The Rev D A3 jumper network selects the target address at startup. This board
should be jumpered as Mouth and report `0x31`.

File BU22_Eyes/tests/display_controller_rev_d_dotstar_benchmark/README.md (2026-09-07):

# Rev D CircuitPython DotStar benchmark

This diagnostic measures the output cost of the standard CircuitPython
`adafruit_dotstar` library with the corrected six-channel Rev D pin mapping.
It uses the full eye-controller load of 144 pixels per channel.

For every channel it reports:

- Whether the library acquired `busio.SPI` or fell back to software GPIO
- Average milliseconds per `show()`
- Maximum theoretical FPS for that channel alone

It then measures the complete sequential six-channel `show()` operation and
reports whether it fits within the 100 ms budget required for 10 FPS. The test
repeats every five seconds. Connected tiles may briefly show a dim amber color
during each benchmark and are returned to black afterward.

The backend report reads the library's private `_spi` field and is intended
only for this controlled diagnostic. It should not become a production API
dependency.

Copy `code.py` and `config.py` to `CIRCUITPY`. Confirm that
`adafruit_dotstar.mpy` and `adafruit_pixelbuf.mpy` are installed under `lib/`.

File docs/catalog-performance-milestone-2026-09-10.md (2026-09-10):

# Simulator catalog and synchronized performance milestone

Date: 2026-09-10

The Rev D Eyes controller, Mouth controller, Brain, and Audio FX board have now
completed the first end-to-end performance generated by Bender Expression Lab.
This establishes the working content path from authored simulator frames to
button-triggered physical playback.

## Validated behavior

- The simulator exports separate Eyes, Mouth, Performance, Audio, and Audio FX
  deployment catalogs for the Rev D development geometry.
- Audio events retain stable semantic IDs while the deployment manifest maps
  the installed subset onto `T00.WAV` through `T99.WAV` slots.
- A build-time converter generates compact CircuitPython modules. Display
  controllers do not parse the larger JSON exports at runtime.
- Both display controllers can browse their exported content locally in
  Bender mode and accept named animation commands in Target mode.
- The Brain Play menu browses exported performances first and individual Eye
  and Mouth animations afterward.
- `PLAY_ANIMATION_TIMED` gives each controller an entry, hold, and exit duration
  in milliseconds. Controllers retime authored frames locally at no more than
  the exported maximum display FPS, leaving I2C free between semantic events.
- The Brain schedules display and Audio FX events from the exported performance
  timeline. Performance 0 played both displays and `T00.WAV` with timing
  reported as visually close on the assembled hardware.
- The controller Normal Eye frame reserves the top two and bottom two rows for
  later shocked/visor movement.

The current hardware result is sufficient to validate the architecture. Exact
inter-controller and audio skew still needs measurement using high-speed video
or logic-analyzer traces before timing tolerances are finalized.

## Deployment safety

Do not trust macOS volume names such as `CIRCUITPY 1`: suffixes can be reassigned
when several boards reboot. Before every installation, read `boot_out.txt` and
match both board type and UID. Install boards sequentially, copy support/data
files first, and copy `code.py` last because writing it triggers a reboot.

Known development hardware identities during this milestone:

- Brain Feather RP2040: `DF6548405F63432D`
- Display-controller KB2040: `DF63CC284F214629`
- Display-controller KB2040: `DF63CC284F66402B`

## Next validation

1. Record the short and long performances at high frame rate with an audible or
   visible timing reference.
2. Measure event dispatch, first displayed frame, and Audio FX onset latency.
3. Decide whether fixed per-device latency compensation belongs in the Brain
   scheduler or in exported deployment settings.
4. Verify interruption, replay, missing-controller, and missing-audio behavior.

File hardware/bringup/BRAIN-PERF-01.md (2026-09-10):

# BRAIN-PERF-01 bring-up record

Last updated: 2026-09-08

## Identity

- Assembly: BU-22 Brain prototype perfboard
- MCU: Adafruit Feather RP2040
- Test source: `BU22_Brain/tests/brain_board_bringup/`

## Status

- Board assembly has been reported complete.
- Basic continuity checks have been reported as passing.
- The Feather identifies as `adafruit_feather_rp2040`, UID
  `DF6548405F63432D`, under CircuitPython 10.2.1.
- The initial powered I2C scan found the VCNL4200 at `0x51` and DS3231 at
  `0x68`. With both Rev D controllers connected and running the scan-only
  target firmware, a later Brain scan found all four expected devices: Eyes at
  `0x30`, Mouth at `0x31`, VCNL4200 at `0x51`, and DS3231 at `0x68`.
- Configuring the DS3231 SQW output for 1 Hz produced nine transitions in 4.5
  seconds, with measured edge intervals of approximately 0.498–0.501 seconds.
- The RTC was set once from the Mac's local wall clock to
  `2026-08-29 11:24:03`, with no timezone or DST conversion. The subsequent
  read matched, and the RTC lost-power flag cleared.
- All seven buttons reported released, Audio FX ACT reported idle/high, and the
  sensor input reported high during the static input-state check.
- Initial named-button testing showed a one-position firmware offset: the
  physical Mode control reported as Button 5, Enter reported as Mode, Up
  reported as Enter, and Down reported as Up. Firmware was reordered from
  those observations so Mode, Enter, Up, and Down use D10, D9, D6, and D5,
  respectively. The function connected to D4 has not yet been identified.
- Retesting confirmed that Mode, Enter, Up, and Down now report their correct
  names in the serial console.
- The Audio FX board returned a list of 14 WAV files, `T00` through `T13`. It
  accepted numbered playback commands, and audible speaker output was
  subsequently reported as passing.
- Pulsing Audio FX reset with the `x` command while a track was playing stopped
  playback as expected, confirming the reset-control path.
- Visible synchronized RTC SQW blinking on the Feather NeoPixel was previously
  confirmed at the bench. The v0.10 test firmware now turns the onboard
  NeoPixel off after startup because a separate physical Brain heartbeat LED
  is connected.
- The physical Brain heartbeat LED has been reported as working.
- Button operation, named-button reporting, numbered Audio FX playback, and
  audible speaker output have been reported as passing. Specific functions
  for the remaining unnamed button inputs have not been recorded.
- Raw VCNL4200 monitoring passed. Reported proximity was approximately 1–3
  with nothing present or at about one foot, and 10 or higher at one foot or
  closer. The sensor INT output has not yet been physically wired to Brain A3.
- With the v0.5 active-low close/away configuration running, the VCNL4200 INT
  pin was subsequently clarified to be continuously at 0 V, not observed to
  transition specifically after a close event. This is consistent with an
  initial away event latching while INT is disconnected from A3 and therefore
  not handled, but the cause has not yet been physically confirmed. v0.6 uses
  close-only mode and clears prior flags for the next direct-pin test.
- The v0.6 close-only test passed: INT asserted at 0 V after the proximity
  threshold was crossed. INT remained low after proximity dropped, confirming
  its expected latched behavior; explicit interrupt-flag acknowledgement is
  required to release it.
- Reading/clearing the latched sensor interrupt with the v0.7 `f` command was
  confirmed to release INT back high. Wiring INT to Brain A3 is intentionally
  deferred.
- The physical red antenna was connected and the v0.9 three-second red-output
  test passed. The green and blue/spare antenna output tests were subsequently
  reported as passing as well.
- The unpowered D1 direction check, USB-only isolation test, and external-5 V-
  only power test were reported as passing. Exact voltage, diode-drop, and
  supply-current measurements were not provided and are not inferred here.
- Brain firmware v0.11 successfully commanded Eyes Normal/Angry at `0x30` and
  Mouth Normal/Open at `0x31`. The requested image shapes looked correct; the
  Mouth controller's CH4 tile remained dark and requires separate isolation.
- In the later all-six-channel Mouth diagnostic firmware, the Brain continued
  commanding the static Mouth states and CH1 through CH4 each passed with the
  same moved tile. The earlier CH4 failure did not persist.
- Brain firmware v0.12 passed the integrated stored-performance test. The `g`
  menu command looped an eight-second, 10 FPS timeline and sent matching frame
  tags to Eyes `0x30` and Mouth `0x31`. Eyes looked left, held, looked right,
  returned to center, and held; Mouth cycled through five stored openness
  levels. The combined visual result was reported working successfully.

## Planned checks

- I2C pull-up electrical measurements
- Sensor INT-to-A3 integration and away-event handling are deferred
- Continue the successful stored-frame Eyes/Mouth command path into simulator
  export and higher-level Brain states

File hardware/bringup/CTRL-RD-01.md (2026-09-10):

# CTRL-RD-01 bring-up record

Last updated: 2026-09-09

## Identity

- Assembly: first hand-assembled universal display controller
- PCB: BU-22 Display Controller Rev D
- MCU: socketed Adafruit KB2040
- KB2040 UID observed over USB: `DF63CC284F66402B`
- Current development role: Mouth controller
- Intended initial role: standalone controller hardware validation

## Assembly notes

- D1 and D2 were initially installed according to incorrect `+` silkscreen
  marks and were subsequently rotated 180 degrees.
- Correct LED polarity is left square pad 1 = cathode/GND and right round pad 2
  = anode/positive.
- See `hardware/display-controller-rev-d/ERRATA.md`.

## Tests passed

- Input `SYSTEM_5V` to GND did not show a hard short. Resistance increased from
  approximately 2 kOhm through 3 kOhm and 4 kOhm as the capacitors charged from
  the meter.
- With only external 5 V connected, all six channel power pins measured as
  expected.
- U2 and U3 logic-supply measurements passed.
- Q1 output-enable behavior passed with the KB2040 and temporary test firmware:
  the collector/OE voltage remained high during the five-second fail-dark
  interval and changed correctly when firmware enabled the buffers.
- With the slow four-phase output exerciser, all six channels on the completed
  board cycle between approximately 0 V and 4.7 V as commanded for both clock
  and data.

## Open issues

- Reflow restored supply voltage at U1 pin 14, but all four U1-buffered outputs
  currently swing only between approximately 0 and 1.5 V instead of reaching
  `LOGIC_5V`. U1 power, ground, OE, and input levels remain to be isolated.
- The heartbeat LED appeared solid because the deployed temporary firmware used
  the KB2040 internal pull-up. Repository source has been corrected but its
  deployment has not yet been recorded.
- After microscope inspection and hot-air/liquid-flux reflow of visible trace
  and solder connections, no obvious remaining physical PCB flaw was observed.
  LED-array testing still passes only U3/CH5 and CH6; U1/CH1 and CH2 and
  U2/CH3 and CH4 do not drive the tested arrays.

## Current firmware source

The deliberately slow valid-DotStar mouth test is being deployed from:
`BU22_Mouth/tests/display_controller_rev_d_slow_dotstar/`

It bypasses `adafruit_dotstar`, sends identical valid 55-pixel frames to all
six channels at a nominal 1 kHz clock, and cycles red, green, blue, dim white,
and black. Only U3/CH5–6 operated; CH1–4 still failed, ruling out excessive
clock rate as the sole cause. Version `0.2-swap-ch1-4` was then prepared and
deployed with clock/data intentionally reversed only on CH1–4. The same mouth
tile then worked on all six channels, confirming the original CH1–4 firmware
clock/data assignments were reversed. The corrected Rev D mapping is now
standardized in repository configurations; see ERRATA E3.

5x11 tooth-module visual test previously deployed:
`BU22_Mouth/tests/display_controller_rev_d_tooth_module/`

It sends identical 55-pixel frames to all six channels, with a sequential
path chase, column sweep, row sweep, conservative all-on colors, and blackout.
The test was deployed to the controller KB2040 for initial use with only the
same tooth module moved between channels. CH5 and CH6 passed visually. CH3 and
CH4 powered the module and showed expected slow/static signal voltages but
produced no visible DotStar output. This localizes the visual/high-speed failure
to the U2 channel group; the specific waveform or hardware cause is unresolved.

The all-channel electrical output exerciser is currently deployed from:
`BU22_Eyes/tests/display_controller_rev_d_output_exerciser/`

It keeps the buffers disabled for five seconds, initializes all Rev D clock and
data GPIOs low, enables the buffers, and repeats four two-second phases across
all six channels: low/low, high/low, low/high, and high/high. Deployment to
KB2040 UID `DF63CC284F66402B` was reconfirmed on 2026-09-06. After reflow work,
both clock and data outputs
are now reported working on CH3 through CH6. CH1 and CH2 remain faulty because
all four U1 outputs swing only from approximately 0 to 1.5 V.
- Follow-up probing reported U2 itself working correctly, including the CH4
  side. Subsequent measurements found the CH4 signals failing across the R7
  and R8 series-resistor paths. Additional path testing indicates an open
  solder-pad connection between U2's CH4 outputs and the U2-side pads of R7/R8.
  Reflow restored CH4, and CH3 through CH6 now pass.
- C1's left pad showed continuity to the known `LOGIC_5V` reference, while the
  C1-left-to-U1-pin-14-lead measurement was approximately 3 MOhm. This confirms
  an effectively open path to the U1 VCC lead; the distinction between an
  unsoldered lead and an open PCB pad/feed remains to be verified after reflow.
- The half-scale static Mouth I2C test was run with three `5 x 11` tiles mapped
  CH6, CH5, and CH4 from physical left to right. Brain-commanded Normal and
  Open images looked correct on the illuminated tiles after shifting the grid
  to repeat three lit rows/columns followed by one dark separator. CH4 produced
  no visible output in this three-tile configuration. This conflicts with its
  earlier successful duplicated-channel visual test; the current tile/cable
  versus channel path has not yet been isolated.
- A subsequent diagnostic version initialized all six DotStar channel objects,
  kept CH6 as the left pattern and CH5 as the center pattern, and duplicated
  the rightmost pattern on CH1 through CH4. Without moving the tile that was
  already connected to CH3, Mouth output began working. Moving the same tile
  through CH1, CH2, CH3, and CH4 then produced correct output on all four
  channels. Initializing/transmitting all six channels is correlated with the
  recovery, but the cause of the earlier selective failure is not established.
- The full-capacity mixed automatic-SPI benchmark transmitted 55 pixels on all
  six channels (330 total). Adafruit DotStar selected hardware SPI for CH1 and
  software SPI for CH2–CH6. The completed run measured approximately 204.7 ms
  per rendered controller frame (4.89 FPS maximum; 3.91 FPS at the 80% budget),
  missed every scheduled deadline from 10 through 60 FPS, and measured a 1.99×
  clear-then-show penalty. The attached CH4–CH6 panels visibly showed moving
  colored pixels; no visual frame-rate measurement is inferred.
- The later one-GPIO-at-a-time mapping test on `CTRL-RD-02` established that
  physical CH1–CH4 are reversed across the MCU socket: CH1 `C/D` is `D8/D9`,
  CH2 is `D6/D7`, CH3 is `D4/D5`, and CH4 is `D2/D3`. This mapping applies to
  both Rev D assemblies; the earlier identical-channel tests could not expose
  the permutation.
- The Mouth controller's two-chain hardware-SPI test passed visually at 4 MHz
  using CH4 for SPI0 and CH5 clock plus CH6 data for SPI1. The two 55-pixel
  chains remained visually in sync with the identical moving-pixel pattern.
- The complete half-size Mouth array, three daisy-chained 5x11 tiles (165
  pixels), passed the combined CH5-clock/CH6-data SPI1 test at 4 MHz. The full
  chase and solid-color sequence were reported working well.
- The geometry-aware tiled line scan passed visually at 10 FPS across the same
  15x11 Mouth array. The horizontal line remained continuous across all three
  independently serpentine-wired tiles, and the vertical scan also looked
  correct.
- The integrated I2C stored-frame receiver passed with Brain v0.12. The Brain
  sent tagged frame commands at 10 FPS while this controller rendered five
  distinct Mouth openness levels locally across the 165-pixel SPI1 chain at
  4 MHz. The repeating eight-second performance was reported working.

The scan-only target test remains available at:
`BU22_Eyes/tests/display_controller_rev_d_i2c_target/`

The test keeps all AHCT outputs disabled, uses the Rev D RX/TX I2C routing,
and selects `0x30` through `0x33` from the A3 address network. Deployment to
the controller KB2040 was confirmed. Open/open correctly decodes as Eyes, and
the top-row A0 shunt correctly decodes as Mouth. The bottom-row A1 shunt does
not produce its expected Spare selection. Raw ADC values have not yet been
provided. Brain discovery and the remaining A1/both-shunts address levels are
unconfirmed.

Target test v0.2 changes the intended state mapping: one A1/left-role shunt is
Eyes `0x30`, one A0/right-role shunt is Mouth `0x31`, no shunts is Development
`0x33`, and both shunts is Spare `0x32`. With CTRL-RD-01 selected as Mouth and
running this target firmware, the Brain discovered it at `0x31` in a complete
four-device scan. The Development, Spare, and raw ADC levels remain unobserved.

JP1 was confirmed to have a Rev D copper/label orientation error. The intended
interface is one vertical left-column shunt for Eyes and one vertical
right-column shunt for Mouth, with none and both reserved for extra states.
Fabricated Rev D boards only select their resistor paths with horizontal row
shunts. See `hardware/display-controller-rev-d/ERRATA.md` E2.

## Next test

1. Preserve all-six-channel initialization while developing the integrated
   controller firmware and watch for recurrence of selective output loss.
2. Continue controller development using the complete 165-pixel Mouth array on
   the combined CH5-clock/CH6-data SPI1 chain.
3. Correct MCU1B socket pad numbering/orientation against actual KB2040 pin names
   before releasing the next PCB revision.
4. Do not treat the 0/4.7 V static pass as a dynamic LED-array pass.
5. Record the target test's remaining A1/both-shunts ADC levels.
6. Redeploy the corrected standalone heartbeat-input firmware.
7. Connect additional LED modules only after all channel faults pass.

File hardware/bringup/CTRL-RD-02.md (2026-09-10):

# CTRL-RD-02 bring-up record

Last updated: 2026-09-09

## Identity

- Assembly: second hand-assembled universal display controller
- PCB: BU-22 Display Controller Rev D
- MCU: socketed Adafruit KB2040
- KB2040 UID observed over USB: `DF63CC284F214629`
- Intended initial role: standalone controller and single eye-tile validation

## Connected hardware

- One `9 x 16` eye tile is connected to one controller channel.
- The previous controller remains associated with one mouth tile; no result
  for that board is inferred by this test.

## Assembly notes

- Assembly used a hot-air rework station, liquid flux, and microscope
  inspection.
- No obvious board, trace, or soldering flaw was visible under the microscope.

## Firmware deployed

The dedicated eye-tile visual test was deployed from:
`BU22_Eyes/tests/display_controller_rev_d_eye_tile/`

The deployed `code.py` and `config.py` were verified byte-for-byte against the
repository copies. The test addresses 144 pixels per channel and sends
identical frames to all six Rev D outputs. It assumes a top-left-origin,
column-serpentine tile, runs a sequential chain chase, logical column and row
sweeps, conservative solid-color fills, and blackout, and retains the
five-second fail-dark startup interval.

The tile's static Bender-eye pattern was physically reported to look good. A
dedicated 10 FPS repeating blink test was subsequently deployed from
`BU22_Eyes/tests/display_controller_rev_d_eye_blink/`; its physical animation
result remains pending.

The slow all-channel electrical output exerciser was deployed afterward from
`BU22_Eyes/tests/display_controller_rev_d_output_exerciser/` to KB2040 UID
`DF63CC284F214629`. The deployed files were verified byte-for-byte against the
repository copies. New electrical measurements remain pending.

After the CH1–CH4 clock/data mapping correction was validated on CTRL-RD-01,
the corrected `9 x 16` eye-tile visual test was deployed to this controller.
The deployed `code.py` and corrected `config.py` were verified byte-for-byte;
dynamic CH1–CH6 results remain pending.

## Tests passed

- The centered Bender-style eye pattern looks good on the temporary `9 x 16`
  strip-built eye tile.
- LED-array operation passes on U3/CH5 and CH6.
- With the slow four-phase output exerciser, all six channels cycle between
  approximately 0 V and 4.7 V as commanded for both clock and data.
- With the corrected Rev D clock/data mapping, the known-good `9 x 16` eye tile
  visually operates across CH1 through CH6. This confirms dynamic LED-array
  operation through U1, U2, and U3 on the second assembly.
- With CTRL-RD-02 selected as Eyes and running the scan-only I2C target
  firmware, the Brain discovered it at `0x30` in a complete four-device scan
  alongside Mouth `0x31`, VCNL4200 `0x51`, and DS3231 `0x68`.
- The half-scale static Eyes I2C test passed visually with the physical left eye
  on CH6 and right eye on CH5. Brain commands selected Normal and static Angry
  images successfully. Keeping the first and last logical rows dark produced
  the desired less-open eye shape.
- The final half-scale eye geometry was visually confirmed: both tiles use the
  same symmetric eight-column image starting at the local left edge, leave the
  ninth/rightmost column unused, and use a centered two-column-by-four-row dark
  pupil. Normal and Angry appearance were accepted at the bench.
- The full-capacity mixed automatic-SPI benchmark transmitted 144 pixels on
  CH3–CH6 (576 total). Adafruit DotStar selected hardware SPI for CH3 and
  software SPI for CH4–CH6. The completed runs measured approximately 315–318
  ms per controller frame (about 3.1 FPS maximum; about 2.5 FPS at the 80%
  budget), missed every scheduled deadline from 10 through 60 FPS, and measured
  a 2.0× clear-then-show penalty. The attached CH5/CH6 panels visibly showed
  moving colored pixels; no visual frame-rate measurement is inferred.
- A one-GPIO-at-a-time meter test established the physical CH1–CH4 socket
  mapping: CH1 `C/D` is `D8/D9`, CH2 is `D6/D7`, CH3 is `D4/D5`, and CH4 is
  `D2/D3`. The earlier identical-all-channel tests could not reveal this
  channel-order reversal.
- Dual hardware SPI passed visually at both 500 kHz and 4 MHz with one eye on
  CH4 (`D2` clock, `D3` data / SPI0) and the other using CH5 clock plus CH6
  data (`A0` clock, `A1` data / SPI1). Both chains remained visually in sync
  with an identical moving-pixel pattern at 4 MHz.
- The complete half-size Eyes array, two daisy-chained 9x16 panels (288
  pixels), passed the combined CH5-clock/CH6-data SPI1 test at 4 MHz. The full
  chase and solid-color sequence were reported working well.
- The geometry-aware tiled line scan passed visually at 10 FPS across the same
  18x16 Eyes array. The horizontal line remained continuous across both
  independently serpentine-wired panels, and the vertical scan also looked
  correct.
- The integrated I2C stored-frame receiver passed with Brain v0.12. The Brain
  sent tagged frame commands at 10 FPS while this controller rendered stored
  left, center, and right eye positions locally across the 288-pixel SPI1 chain
  at 4 MHz. The repeating eight-second performance was reported working.

## Open issues

- CircuitPython's six-channel software DotStar output does not sustain the
  intended 10 FPS animation rate. This is a firmware-performance issue and is
  separate from the now-passed channel hardware and corrected pin mapping.

## Open observations

- Record which controller channel is connected.
- Confirm whether all 144 pixels respond during the physical-chain chase.
- Confirm the apparent start corner and chain direction.
- Confirm that logical column and row sweeps match the physical tile.
- Confirm red, green, blue, dim white, and blackout behavior.
- Record any dead, stuck, miscolored, or incorrectly mapped pixels without
  inferring a cause.

## Next test

Continue controller development using the complete 288-pixel Eyes array on the
combined CH5-clock/CH6-data SPI1 chain.

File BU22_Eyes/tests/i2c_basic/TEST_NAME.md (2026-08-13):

# Universal I2C validation receiver

This folder contains the Eyes-side receiver used by every numbered test in
`BU22_Brain/tests/i2c_validation/`. It deliberately retains all raw commands
that were proven during breadboard development. It is test firmware, not the
final BU-22 Eyes protocol or production firmware.

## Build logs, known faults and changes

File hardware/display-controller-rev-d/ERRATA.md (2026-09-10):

# BU-22 Display Controller Rev D — assembly errata

## E1: D1 and D2 positive silkscreen marks are reversed

Discovered during first-board assembly and bring-up on 2026-08-29.

The PCB copper and footprint pad assignments are correct, but the nearby `+`
silkscreen marks were placed on the cathode side of both 3 mm LEDs.

Correct installation, viewed from the top/component side with the board
silkscreen readable:

| Component | Function | Left square pad 1 | Right round pad 2 |
|---|---|---|---|
| D1 | Green power LED | Cathode / GND / short lead / flat side | Anode / positive / long lead |
| D2 | Red heartbeat LED | Cathode / GND / short lead / flat side | Anode / positive / long lead |

Ignore the printed `+` marks on fabricated Rev D boards. Install both LEDs
with their positive/long leads in the right round pads.

### Required next-revision correction

- Move each `+` mark to the right/round/pad-2 side of its LED.
- Retain the existing electrical pad assignments and routing.
- Add explicit `A` and `K` polarity labels if space permits.
- Include LED silkscreen polarity in the fabrication-release audit.

## E2: JP1 address-selection copper is rotated relative to role labels

Confirmed during first-board bring-up on 2026-08-30.

The Rev D silkscreen places `EYES` to the left of JP1 and `MOUTH` to the right,
which indicates that one vertical shunt should select either role. The copper
instead assigns the 2x2 pads as:

| Physical position | Top | Bottom |
|---|---|---|
| Left column | pad 1 `ADDRESS` | pad 3 `ADDRESS` |
| Right column | pad 2 `ADDR_A0` | pad 4 `ADDR_A1` |

Consequences on fabricated Rev D boards:

- A vertical left shunt only joins `ADDRESS` to `ADDRESS` and has no effect.
- A vertical right shunt joins `ADDR_A0` to `ADDR_A1` without connecting them
  to `ADDRESS` and does not select the intended role.
- Only horizontal row shunts connect `ADDRESS` to a pull-down. The top row
  selects the 10 kOhm path and the bottom row selects the 20 kOhm path.

### Rev D workaround

Use the horizontal rows for electrical testing despite the role labels:

| Shunts | Temporary Rev D test role/address |
|---|---|
| None | Development `0x33` |
| Top horizontal row | Mouth `0x31` |
| Bottom horizontal row | Eyes `0x30` |
| Both horizontal rows | Spare `0x32` |

### Required next-revision correction

Route JP1 so each labeled vertical column connects `ADDRESS` to one resistor
path:

- Left vertical column: Eyes `0x30`
- Right vertical column: Mouth `0x31`
- No shunt: Development `0x33`
- Both vertical shunts: Spare `0x32`

One implementation is to connect pads 1 and 2 to `ADDRESS`, pad 3 to one
address pull-down, and pad 4 to the other. Confirm the final footprint
orientation and pad numbering against the physical board before release.

## E3: Original firmware reversed CH1–CH4 clock and data assignments

Confirmed on `CTRL-RD-01` during bring-up on 2026-09-06.

The original Rev D CircuitPython configurations treated D3/D5/D7/D9 as clock
and D2/D4/D6/D8 as data. With that mapping, a known-good 55-pixel mouth tile
worked only on U3/CH5 and CH6. All six channels nevertheless passed a slow
static 0 V/4.7 V output exerciser.

A deliberately slow valid-DotStar test at approximately 1 kHz still operated
only CH5/CH6. Reversing clock and data in firmware only for CH1–CH4 made the
same mouth tile work on all six channels. Because that test sent identical
data to every output, it could confirm signal roles but not channel order. A
later one-GPIO-at-a-time meter test established the complete physical mapping:

| Channel | Clock | Data |
|---|---|---|
| CH1 | D8 | D9 |
| CH2 | D6 | D7 |
| CH3 | D4 | D5 |
| CH4 | D2 | D3 |
| CH5 | A0 | SCK |
| CH6 | A2 | A1 |

For CH1 through CH4, the connector positions printed `C` and `D` carry the
even and odd GPIOs shown above and operate as clock and data. This identifies
both reversed channel ordering in the socket mapping and the earlier firmware
clock/data error; it does not show defective U1/U2 buffers or failed PCB
traces. Repository Rev D firmware now uses the fully observed mapping.

### Required next-revision correction

- Preserve the validated functional mapping and reversed CH1–CH4 channel order
  in controller firmware.
- Annotate the KB2040 socket symbols with their actual board pin names.
- Audit MCU1B socket pad numbering/orientation against the installed KB2040.
- Ensure the schematic, PCB net names, firmware mapping, and connector labels
  all describe the same clock/data signals before the next fabrication release.
- For Rev E, route each of the RP2040's two hardware SPI buses to a complete,
  correctly labeled output connector. Rev D development may use CH4 for SPI0
  and the combined CH5-clock/CH6-data path for SPI1.

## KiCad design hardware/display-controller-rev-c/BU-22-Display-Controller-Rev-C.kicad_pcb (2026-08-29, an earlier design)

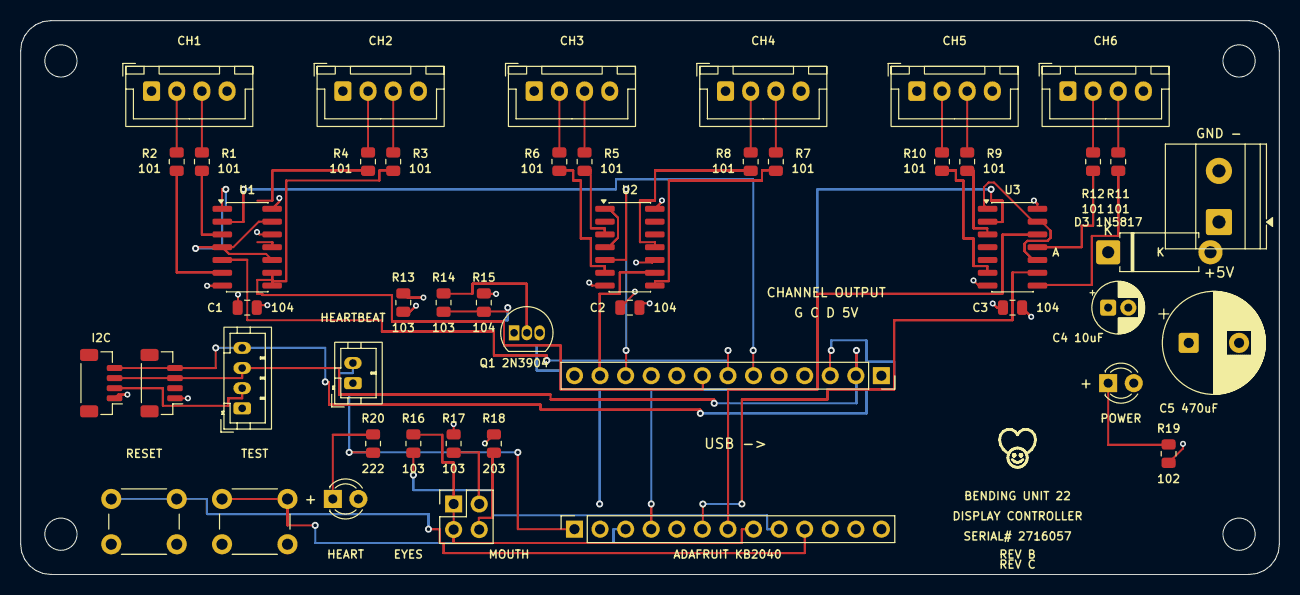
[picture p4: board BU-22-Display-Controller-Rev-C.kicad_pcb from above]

Board: 4 copper layers, 125.0 x 55.0 mm, 52 parts (0 on the bottom side), 52 nets.

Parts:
C1, C2, C3: 100nF; C_0805_2012Metric
C4: 10uF; CP_Radial_D5.0mm_P2.00mm
C5: 470uF; CP_Radial_D10.0mm_P5.00mm
D1: GREEN POWER; LED_D3.0mm
D2: RED HEARTBEAT; LED_D3.0mm
D3: 1N5817 LOGIC ISOLATION; D_DO-15_P10.16mm_Horizontal
H1, H2, H3, H4: M3; MountingHole_3.2mm_M3
J1: CH1; JST_XH_B4B-XH-A_1x04_P2.50mm_Vertical
J2: CH2; JST_XH_B4B-XH-A_1x04_P2.50mm_Vertical
J3: CH3; JST_XH_B4B-XH-A_1x04_P2.50mm_Vertical
J4: CH4; JST_XH_B4B-XH-A_1x04_P2.50mm_Vertical
J5: CH5; JST_XH_B4B-XH-A_1x04_P2.50mm_Vertical
J6: CH6; JST_XH_B4B-XH-A_1x04_P2.50mm_Vertical
J7: 5V INPUT; TerminalBlock_Phoenix_MKDS-1,5-2-5.08_1x02_P5.08mm_Horizont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
J8: I2C TO BRAIN; JST_SH_BM04B-SRSS-TB_1x04-1MP_P1.00mm_Vertical
J9: I2C THRU; JST_SH_BM04B-SRSS-TB_1x04-1MP_P1.00mm_Vertical
J10: I2C TEST; JST_PH_B4B-PH-K_1x04_P2.00mm_Vertical
J11: GND HEARTBEAT; JST_PH_B2B-PH-K_1x02_P2.00mm_Vertical
JP1: ADDRESS; PinHeader_2x02_P2.54mm_Vertical
MCU1A: KB2040 ROW A; PinSocket_1x13_P2.54mm_Vertical
MCU1B: KB2040 ROW B; PinSocket_1x13_P2.54mm_Vertical
Q1: 2N3904 OE; TO-92_Inline
R1, R3, R5, R7, R9, R11: 100R DATA; R_0805_2012Metric
R2, R4, R6, R8, R10, R12: 100R CLOCK; R_0805_2012Metric
R13, R14, R16, R17: 10k; R_0805_2012Metric
R15: 100k; R_0805_2012Metric
R18: 20k; R_0805_2012Metric
R19: 1k; R_0805_2012Metric
R20: 2k2; R_0805_2012Metric
SW1: TEST; SW_PUSH_6mm
SW2: RESET; SW_PUSH_6mm
U1, U2, U3: 74AHCT125D; SOIC-14_3.9x8.7mm_P1.27mm

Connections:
3V3_LOCAL: MCU1A.9, R16.1
+5V: C1.1, C2.1, C3.1, C4.1, C5.1, J1.4, J2.4, J3.4, J4.4, J5.4, J6.4, J7.1, MCU1A.12, R13.1, R19.1, U1.14, U2.14, U3.14
ADDRESS: JP1.1, JP1.3, MCU1A.8, R16.2
ADDR_A0: JP1.2, R17.1
ADDR_A1: JP1.4, R18.1
CH1_CLOCK_3V3: MCU1B.7, U1.5
CH1_CLOCK_5V: R2.1, U1.6
CH1_CLOCK_OUT: J1.2, R2.2
CH1_DATA_3V3: MCU1B.6, U1.2
CH1_DATA_5V: R1.1, U1.3
CH1_DATA_OUT: J1.3, R1.2
CH2_CLOCK_3V3: MCU1B.9, U1.12
CH2_CLOCK_5V: R4.1, U1.11
CH2_CLOCK_OUT: J2.2, R4.2
CH2_DATA_3V3: MCU1B.8, U1.9
CH2_DATA_5V: R3.1, U1.8
CH2_DATA_OUT: J2.3, R3.2
CH3_CLOCK_3V3: MCU1B.11, U2.5
CH3_CLOCK_5V: R6.1, U2.6
CH3_CLOCK_OUT: J3.2, R6.2
CH3_DATA_3V3: MCU1B.10, U2.2
CH3_DATA_5V: R5.1, U2.3
CH3_DATA_OUT: J3.3, R5.2
CH4_CLOCK_3V3: MCU1B.13, U2.12
CH4_CLOCK_5V: R8.1, U2.11
CH4_CLOCK_OUT: J4.2, R8.2
CH4_DATA_3V3: MCU1B.12, U2.9
CH4_DATA_5V: R7.1, U2.8
CH4_DATA_OUT: J4.3, R7.2
CH5_CLOCK_3V3: MCU1A.5, U3.5
CH5_CLOCK_5V: R10.1, U3.6
CH5_CLOCK_OUT: J5.2, R10.2
CH5_DATA_3V3: MCU1A.4, U3.2
CH5_DATA_5V: R9.1, U3.3
CH5_DATA_OUT: J5.3, R9.2
CH6_CLOCK_3V3: MCU1A.7, U3.12
CH6_CLOCK_5V: R12.1, U3.11
CH6_CLOCK_OUT: J6.2, R12.2
CH6_DATA_3V3: MCU1A.6, U3.9
CH6_DATA_5V: R11.1, U3.8
CH6_DATA_OUT: J6.3, R11.2
ENABLE_BASE: Q1.2, R14.2
ENABLE_GPIO: MCU1A.2, R14.1, R15.1
GND: C1.2, C2.2, C3.2, C4.2, C5.2, D1.2, D2.2, J1.1, J2.1, J3.1, J4.1, J5.1, J6.1, J7.2, J8.1, J9.1, J10.1, J11.1, MCU1A.11, MCU1B.4, MCU1B.5, Q1.1, R15.2, R17.2, R18.2, SW1.2, SW2.2, U1.7, U2.7, U3.7
HEARTBEAT: J11.2, MCU1A.1, R20.1
HEART_LED_A: D2.1, R20.2
OE_N: Q1.3, R13.2, U1.1, U1.4, U1.10, U1.13, U2.1, U2.4, U2.10, U2.13, U3.1, U3.4, U3.10, U3.13
PWR_LED_A: D1.1, R19.2
RESET: MCU1A.10, SW2.1
SCL: J8.4, J9.4, J10.4, MCU1B.3
SDA: J8.3, J9.3, J10.3, MCU1B.2
TEST: MCU1A.3, SW1.1

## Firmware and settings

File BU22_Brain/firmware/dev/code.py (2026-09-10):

"""Button-driven BU-22 Brain development runtime."""

import time

import board
import busio
import digitalio
import keypad
import microcontroller
import random
import supervisor

import animation_catalog
import config
from common.brain_state import (
    AntennaSequence,
    BrainState,
    MODE_BENDER,
    MODE_CLOCK,
    MODE_NAMES,
    MODE_PLAY,
    MODE_SETTINGS,
    MODE_TEST,
    TEST_ANTENNA,
    TEST_NAMES,
    TEST_RTC,
)
from common import protocol
from common.brain_settings import (
    COLON_FLASH,
    ClockSettings,
    ZONE_LABELS,
    local_hour,
    utc_hour,
)


supervisor.runtime.autoreload = False
RTC_CONTROL_REGISTER = 0x0E
RTC_SQW_1HZ_MASK = 0x1C

SETTING_DST = 0
SETTING_ZONE = 1
SETTING_FORMAT = 2
SETTING_HOUR = 3
SETTING_MINUTE = 4
SETTING_AMPM = 5
SETTING_COLON = 6
SETTING_EXIT = 7


def log(*values):
    if config.LOGGING:
        print(*values)


def i2c_lock():
    while not i2c.try_lock():
        time.sleep(0.001)


def scan():
    i2c_lock()
    try:
        return tuple(i2c.scan())
    finally:
        i2c.unlock()


def next_tag():
    global display_tag
    display_tag = (display_tag + 1) & 0xFF
    return display_tag


def write_display(address, payload):
    i2c_lock()
    try:
        i2c.writeto(address, payload)
    except OSError as error:
        log("I2C WRITE ERROR 0x%02X" % address, repr(error))
        return False
    finally:
        i2c.unlock()
    if config.MIRROR_I2C:
        log("I2C TX 0x%02X" % address, tuple(payload))
    time.sleep(config.I2C_TRANSACTION_GAP)
    return True


def send_visual(address, command, content_id=None):
    return write_display(
        address, protocol.visual_packet(command, next_tag(), content_id)
    )


def send_timed_animation(address, content_id, entry_ms, hold_ms, exit_ms):
    return write_display(
        address,
        protocol.timed_animation_packet(
            next_tag(), content_id, entry_ms, hold_ms, exit_ms),
    )


def send_clock(hour, minute, use_24_hour=False, flash_colon=True):
    flags = (1 if flash_colon else 0) | (2 if use_24_hour else 0)
    return write_display(
        config.EYES_ADDRESS,
        protocol.clock_packet(next_tag(), hour, minute, flags),
    )


def send_label(text, eyes=True, mouth=True):
    tag = next_tag()
    payload = protocol.dev_text_packet(tag, text)
    if eyes:
        write_display(config.EYES_ADDRESS, payload)
    if mouth:
        write_display(config.MOUTH_ADDRESS, payload)


def play_item_count():
    return len(animation_catalog.PERFORMANCES) + len(animation_catalog.ANIMATIONS)


def selected_play_item():
    index = state.play_selection
    if index < len(animation_catalog.PERFORMANCES):
        return "performance", animation_catalog.PERFORMANCES[index]
    return "animation", animation_catalog.ANIMATIONS[
        index - len(animation_catalog.PERFORMANCES)]


def animation_address(target_name):
    return (config.EYES_ADDRESS if target_name == "eyes"
            else config.MOUTH_ADDRESS)


def show_play_selection():
    kind, item = selected_play_item()
    if kind == "performance":
        item_id, name, _duration, _events = item
        send_label("P " + name)
        log("PLAY SELECT PERFORMANCE", item_id, name)
    else:
        animation_id, target_name, name, _frame_count = item
        prefix = "E " if target_name == "eyes" else "M "
        send_label(prefix + name)
        log("PLAY SELECT ANIMATION", animation_id, target_name, name)


def play_selected_item():
    kind, item = selected_play_item()
    if kind == "performance":
        start_performance(item, time.monotonic())
    else:
        animation_id, target_name, name, _frame_count = item
        send_visual(animation_address(target_name), protocol.PLAY_ANIMATION,
                    animation_id)
        log("PLAY ANIMATION", animation_id, target_name, name)


def audio_play_slot(slot):
    filename = "T%02d     WAV" % slot
    audio_uart.reset_input_buffer()
    audio_uart.write(("P%s\n" % filename).encode("ascii"))
    log("AUDIO PLAY T%02d.WAV" % slot)


def stop_performance():
    global performance_active, performance_events, performance_event_index
    if performance_active:
        audio_uart.write(b"q\n")
    performance_active = False
    performance_events = ()
    performance_event_index = 0


def start_performance(performance, now):
    global performance_active, performance_started, performance_events
    global performance_event_index, performance_ends
    stop_performance()
    performance_id, name, duration_ms, events = performance
    send_visual(config.EYES_ADDRESS, protocol.SHOW_NORMAL)
    send_visual(config.MOUTH_ADDRESS, protocol.SHOW_NORMAL)
    performance_active = True
    performance_started = now
    performance_events = events
    performance_event_index = 0
    performance_ends = now + duration_ms / 1000
    log("PERFORMANCE START", performance_id, name, duration_ms)


def update_performance(now):
    global performance_active, performance_event_index
    elapsed_ms = int((now - performance_started) * 1000)
    while (performance_event_index < len(performance_events)
           and performance_events[performance_event_index][0] <= elapsed_ms):
        event = performance_events[performance_event_index]
        _start_ms, kind, target_or_audio, content_or_slot, entry, hold, exit_ms = event
        if kind == 0:
            address = (config.EYES_ADDRESS if target_or_audio == 1
                       else config.MOUTH_ADDRESS)
            send_timed_animation(address, content_or_slot, entry, hold, exit_ms)
        else:
            audio_play_slot(content_or_slot)
        performance_event_index += 1
    if now >= performance_ends:
        performance_active = False
        log("PERFORMANCE COMPLETE")


def schedule_bender_animation(now):
    global next_bender_animation, last_bender_animation
    choices = animation_catalog.ANIMATIONS
    selected = random.choice(choices)
    if len(choices) > 1:
        while selected[0] == last_bender_animation:
            selected = random.choice(choices)
    animation_id, target_name, name, frame_count = selected
    send_visual(animation_address(target_name), protocol.PLAY_ANIMATION,
                animation_id)
    last_bender_animation = animation_id
    playback_seconds = frame_count / animation_catalog.DEFAULT_ANIMATION_FPS
    next_bender_animation = (
        now + playback_seconds
        + random.uniform(config.BENDER_MIN_PAUSE_SECONDS,
                         config.BENDER_MAX_PAUSE_SECONDS)
    )
    log("BENDER", animation_id, target_name, name,
        "next=%.2f" % next_bender_animation)


def read_display_status(address):
    response = bytearray(20)
    i2c_lock()
    try:
        i2c.readfrom_into(address, response)
    except OSError as error:
        log("I2C STATUS ERROR 0x%02X" % address, repr(error))
        return None
    finally:
        i2c.unlock()
    if response[0] != protocol.MAGIC:
        log("BAD STATUS 0x%02X" % address, tuple(response))
        return None
    mode = protocol.local_mode_from_status(response[6], response[16])
    log(
        "STATUS 0x%02X" % address,
        "mode=", protocol.local_mode_name(mode),
        "display=", response[7],
        "error=", response[11],
    )
    return response


def rtc_device():
    import adafruit_ds3231
    return adafruit_ds3231.DS3231(i2c)


def configure_rtc_sqw(rtc):
    register = bytearray((RTC_CONTROL_REGISTER,))
    control = bytearray(1)
    with rtc.i2c_device as device:
        device.write_then_readinto(register, control)
        control[0] &= ~RTC_SQW_1HZ_MASK
        device.write(bytearray((RTC_CONTROL_REGISTER, control[0])))
    log("RTC SQW configured for 1 Hz")


def current_time():
    if rtc is None:
        return None
    try:
        return rtc.datetime
    except Exception as error:
        log("RTC READ ERROR", repr(error))
        return None


def set_antenna_output(index):
    for output_index, output in enumerate(antenna_outputs):
        output.value = index == output_index
    log("ANTENNA", "OFF" if index is None else config.ANTENNA_NAMES[index])


def stop_active_test():
    antenna_test.stop()
    set_antenna_output(None)


def show_clock(force=False):
    global last_clock_minute
    value = current_time()
    if value is None:
        return
    hour = local_hour(value.tm_hour, settings.timezone, settings.dst)
    key = (hour, value.tm_min, settings.use_24_hour, settings.colon_mode)
    if force or key != last_clock_minute:
        send_clock(hour, value.tm_min, settings.use_24_hour,
                   settings.colon_mode == COLON_FLASH)
        last_clock_minute = key
        log("CLOCK", "%02d:%02d" % (hour, value.tm_min))


def enter_mode(mode):
    global staged_time, setting_index, settings_last_activity
    global last_clock_minute, rtc_test_active, next_bender_animation
    stop_performance()
    stop_active_test()
    rtc_test_active = False
    log("MODE", MODE_NAMES[mode])
    send_label(MODE_NAMES[mode])
    time.sleep(config.MODE_ANNOUNCEMENT_SECONDS)
    if mode == MODE_CLOCK:
        last_clock_minute = None
        send_visual(config.MOUTH_ADDRESS, protocol.SET_OFF)
        show_clock(force=True)
    elif mode == MODE_SETTINGS:
        value = current_time()
        if value is not None:
            staged_time = [
                local_hour(value.tm_hour, settings.timezone, settings.dst),
                value.tm_min,
            ]
            setting_index = SETTING_DST
            settings_last_activity = time.monotonic()
            send_visual(config.MOUTH_ADDRESS, protocol.SET_OFF)
            show_setting()
    elif mode == MODE_BENDER:
        send_visual(config.EYES_ADDRESS, protocol.SHOW_NORMAL)
        send_visual(config.MOUTH_ADDRESS, protocol.SHOW_NORMAL)
        next_bender_animation = time.monotonic()
    elif mode == MODE_PLAY:
        send_visual(config.EYES_ADDRESS, protocol.SET_OFF)
        send_visual(config.MOUTH_ADDRESS, protocol.SET_OFF)
        show_play_selection()
    elif mode == MODE_TEST:
        log("TEST SELECT", TEST_NAMES[state.test_selection])


def show_setting():
    if setting_index == SETTING_DST:
        send_label("DST " + ("ON" if settings.dst else "OFF"))
    elif setting_index == SETTING_ZONE:
        send_label("ZONE " + ZONE_LABELS[settings.timezone])
    elif setting_index == SETTING_FORMAT:
        send_label("24 HOUR" if settings.use_24_hour else "12 HOUR")
    elif setting_index in (SETTING_HOUR, SETTING_MINUTE):
        send_visual(config.MOUTH_ADDRESS, protocol.SET_OFF)
        send_clock(staged_time[0], staged_time[1], settings.use_24_hour,
                   settings.colon_mode == COLON_FLASH)
    elif setting_index == SETTING_AMPM:
        send_label("PM" if staged_time[0] >= 12 else "AM")
    elif setting_index == SETTING_COLON:
        send_label("COLON " + (
            "FLASH" if settings.colon_mode == COLON_FLASH else "SOLID"
        ))
    else:
        send_label("EXIT")


def refresh_staged_hour():
    if staged_time is None:
        return
    value = current_time()
    if value is not None:
        staged_time[0] = local_hour(
            value.tm_hour, settings.timezone, settings.dst)


def adjust_setting(delta):
    if setting_index == SETTING_DST:
        settings.dst = not settings.dst
        settings.save(microcontroller.nvm)
        refresh_staged_hour()
    elif setting_index == SETTING_ZONE:
        settings.timezone = (settings.timezone + delta) % len(ZONE_LABELS)
        settings.save(microcontroller.nvm)
        refresh_staged_hour()
    elif setting_index == SETTING_FORMAT:
        settings.use_24_hour = not settings.use_24_hour
        settings.save(microcontroller.nvm)
    elif setting_index == SETTING_HOUR:
        staged_time[0] = (staged_time[0] + delta) % 24
    elif setting_index == SETTING_MINUTE:
        staged_time[1] = (staged_time[1] + delta) % 60
    elif setting_index == SETTING_AMPM:
        staged_time[0] = (staged_time[0] + 12) % 24
    elif setting_index == SETTING_COLON:
        settings.colon_mode = (settings.colon_mode + delta) % 2
        settings.save(microcontroller.nvm)
    show_setting()


def commit_staged_time():
    if staged_time is None or rtc is None:
        return
    old = rtc.datetime
    rtc.datetime = time.struct_time((
        old.tm_year, old.tm_mon, old.tm_mday,
        utc_hour(staged_time[0], settings.timezone, settings.dst),
        staged_time[1], 0,
        old.tm_wday, old.tm_yday, old.tm_isdst,
    ))
    log("RTC SET LOCAL", "%02d:%02d" % tuple(staged_time))


def next_setting():
    global setting_index
    if setting_index == SETTING_EXIT:
        state.mode = MODE_CLOCK
        enter_mode(MODE_CLOCK)
        return
    setting_index += 1
    if setting_index == SETTING_AMPM and settings.use_24_hour:
        setting_index = SETTING_COLON
    if setting_index == SETTING_COLON:
        commit_staged_time()
    show_setting()


def start_selected_test():
    global rtc_test_active, last_clock_minute
    if state.test_selection == TEST_RTC:
        rtc_test_active = not rtc_test_active
        if rtc_test_active:
            last_clock_minute = None
            send_label("RTC", eyes=False)
            show_clock(force=True)
            log("RTC TEST START; flashing colon confirms display clock activity")
        else:
            send_visual(config.EYES_ADDRESS, protocol.SET_OFF)
            log("RTC TEST STOP")
    elif state.test_selection == TEST_ANTENNA:
        rtc_test_active = False
        send_label("ANTENNA")
        set_antenna_output(antenna_test.start(time.monotonic()))
        log("ANTENNA TEST START: three RGB cycles")


def button_pressed(key_number):
    global rtc_test_active, settings_last_activity
    if key_number == config.MODE_BUTTON:
        state.next_mode()
        enter_mode(state.mode)
    elif state.mode == MODE_SETTINGS:
        settings_last_activity = time.monotonic()
        if key_number == config.UP_BUTTON:
            adjust_setting(1)
        elif key_number == config.DOWN_BUTTON:
            adjust_setting(-1)
        elif key_number == config.ENTER_BUTTON:
            next_setting()
    elif state.mode == MODE_TEST:
        if key_number == config.UP_BUTTON:
            stop_active_test()
            rtc_test_active = False
            state.select_next_test(-1)
            send_label("TEST " + TEST_NAMES[state.test_selection])
            log("TEST SELECT", TEST_NAMES[state.test_selection])
        elif key_number == config.DOWN_BUTTON:
            stop_active_test()
            rtc_test_active = False
            state.select_next_test(1)
            send_label("TEST " + TEST_NAMES[state.test_selection])
            log("TEST SELECT", TEST_NAMES[state.test_selection])
        elif key_number == config.ENTER_BUTTON:
            start_selected_test()
    elif state.mode == MODE_PLAY:
        if key_number == config.UP_BUTTON:
            stop_performance()
            state.select_next_play_item(play_item_count(), -1)
            show_play_selection()
        elif key_number == config.DOWN_BUTTON:
            stop_performance()
            state.select_next_play_item(play_item_count(), 1)
            show_play_selection()
        elif key_number == config.ENTER_BUTTON:
            play_selected_item()


log("BU-22 BRAIN DEVELOPMENT RUNTIME")
i2c = busio.I2C(config.I2C_SCL, config.I2C_SDA,
                frequency=config.I2C_FREQUENCY)
audio_uart = busio.UART(
    config.AUDIO_TX, config.AUDIO_RX,
    baudrate=config.AUDIO_BAUDRATE,
    timeout=0,
    receiver_buffer_size=512,
)
buttons = keypad.Keys(config.BUTTON_PINS, value_when_pressed=False,
                      pull=True, interval=0.02)
sqw = digitalio.DigitalInOut(config.RTC_SQW)
sqw.switch_to_input(pull=digitalio.Pull.UP)

antenna_outputs = []
for pin in config.ANTENNA_PINS:
    output = digitalio.DigitalInOut(pin)
    output.switch_to_output(value=False)
    antenna_outputs.append(output)

log("Startup delay", config.STARTUP_SCAN_DELAY_SECONDS, "seconds")
time.sleep(config.STARTUP_SCAN_DELAY_SECONDS)
found = scan()
log("I2C FOUND", tuple("0x%02X" % address for address in found))

rtc = None
if config.RTC_ADDRESS in found:
    try:
        rtc = rtc_device()
        configure_rtc_sqw(rtc)
    except Exception as error:
        log("RTC INIT ERROR", repr(error))

for display_address in (config.EYES_ADDRESS, config.MOUTH_ADDRESS):
    if display_address in found:
        read_display_status(display_address)

state = BrainState()
settings = ClockSettings()
settings.load(microcontroller.nvm)
antenna_test = AntennaSequence(repetitions=3)
rtc_test_active = False
last_clock_minute = None
staged_time = None
setting_index = SETTING_DST
settings_last_activity = time.monotonic()
display_tag = 0
next_bender_animation = time.monotonic()
last_bender_animation = None
performance_active = False
performance_started = None
performance_events = ()
performance_event_index = 0
performance_ends = None
enter_mode(state.mode)

while True:
    now = time.monotonic()
    event = buttons.events.get()
    if event is not None and event.pressed:
        log("BUTTON", config.BUTTON_NAMES[event.key_number])
        button_pressed(event.key_number)

    if state.mode == MODE_CLOCK or (
        state.mode == MODE_TEST and rtc_test_active
    ):
        show_clock()

    if state.mode == MODE_BENDER and now >= next_bender_animation:
        schedule_bender_animation(now)

    if state.mode == MODE_PLAY and performance_active:
        update_performance(now)

    if (state.mode == MODE_SETTINGS
            and now - settings_last_activity >= config.SETTINGS_TIMEOUT_SECONDS):
        staged_time = None
        state.mode = MODE_CLOCK
        enter_mode(MODE_CLOCK)

    changed, antenna_index = antenna_test.update(now)
    if changed:
        set_antenna_output(antenna_index)
        if not antenna_test.running:
            log("ANTENNA TEST COMPLETE")

    time.sleep(0.005)

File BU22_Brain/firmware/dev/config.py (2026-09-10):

"""BU-22 Brain stable development-runtime configuration."""

import board

LOGGING = False
MIRROR_I2C = False

I2C_SCL = board.SCL
I2C_SDA = board.SDA
I2C_FREQUENCY = 100_000
I2C_TRANSACTION_GAP = 0.02
STARTUP_SCAN_DELAY_SECONDS = 10.0
MODE_ANNOUNCEMENT_SECONDS = 3.0
SETTINGS_TIMEOUT_SECONDS = 60.0
BENDER_MIN_PAUSE_SECONDS = 1.0
BENDER_MAX_PAUSE_SECONDS = 4.0

AUDIO_TX = board.TX
AUDIO_RX = board.RX
AUDIO_BAUDRATE = 9_600

EYES_ADDRESS = 0x30
MOUTH_ADDRESS = 0x31
RTC_ADDRESS = 0x68
VCNL4200_ADDRESS = 0x51

RTC_SQW = board.D13
ANTENNA_PINS = (board.A0, board.A1, board.A2)
ANTENNA_NAMES = ("RED", "GREEN", "BLUE")

# Bench-verified logical mapping for the installed four-button harness.
BUTTON_PINS = (board.D5, board.D9, board.D6, board.D10)
BUTTON_NAMES = ("MODE", "ENTER", "UP", "DOWN")
MODE_BUTTON = 0
ENTER_BUTTON = 1
UP_BUTTON = 2
DOWN_BUTTON = 3

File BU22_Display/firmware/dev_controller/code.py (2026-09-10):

"""Stable Rev D Eyes/Mouth development-controller runtime."""

import time

import adafruit_dotstar
import analogio
import digitalio
import i2ctarget
import random
import supervisor

import catalog
import config
from common.display_model import (
    DisplayGeometry,
    LocalModeState,
    animation_sequence,
    blank_frame,
    clock_frame,
    local_mode_label,
    retimed_frame_index,
    scrolling_frame_at,
    scrolling_frame_count,
    text_frame,
)
from common import protocol


supervisor.runtime.autoreload = False

BLACK = (0, 0, 0)
TEST_COLORS = (
    (255, 0, 0),
    (0, 255, 0),
    (0, 0, 255),
    config.BENDER_COLOR,
    BLACK,
)


def log(*values):
    if config.LOGGING:
        print(*values)


def read_address_adc(pin, samples=16):
    total = 0
    for _ in range(samples):
        total += pin.value
        time.sleep(0.005)
    return total // samples


def decode_role(value):
    if value < config.BOTH_A0_THRESHOLD:
        return config.SPARE_ADDRESS, None
    if value < config.A0_A1_THRESHOLD:
        return config.MOUTH_ADDRESS, protocol.MODULE_MOUTH
    if value < config.A1_OPEN_THRESHOLD:
        return config.EYES_ADDRESS, protocol.MODULE_EYES
    return config.DEVELOPMENT_ADDRESS, None


def geometry_for(module_type):
    if module_type == protocol.MODULE_EYES:
        return DisplayGeometry(
            config.EYES_MODULE_COUNT,
            config.EYES_MODULE_WIDTH,
            config.EYES_MODULE_HEIGHT,
        )
    return DisplayGeometry(
        config.MOUTH_MODULE_COUNT,
        config.MOUTH_MODULE_WIDTH,
        config.MOUTH_MODULE_HEIGHT,
    )


def show_frame(frame):
    pixels.fill(BLACK)
    for y in range(geometry.height):
        row = y * geometry.width
        for x in range(geometry.width):
            if frame[row + x]:
                pixels[geometry.pixel_index(x, y)] = config.BENDER_COLOR
    pixels.show()


def show_color(color):
    pixels.fill(color)
    pixels.show()


def show_packed_frame(frame):
    pixels.fill(BLACK)
    for logical in range(geometry.pixel_count):
        if frame[logical >> 3] & (1 << (7 - (logical & 7))):
            x = logical % geometry.width
            y = logical // geometry.width
            pixels[geometry.pixel_index(x, y)] = config.BENDER_COLOR
    pixels.show()


def show_scrolling_text(text, seconds):
    frame_count = scrolling_frame_count(geometry, text)
    count = max(1, int(seconds * config.STARTUP_TEXT_FPS))
    started = time.monotonic()
    for step in range(count):
        index = min(frame_count - 1, step * frame_count // count)
        show_frame(scrolling_frame_at(geometry, text, index))
        deadline = started + ((step + 1) / config.STARTUP_TEXT_FPS)
        remaining = deadline - time.monotonic()
        if remaining > 0:
            time.sleep(remaining)


def start_message(text, duration=config.MODE_ANNOUNCEMENT_SECONDS,
                  mode_announcement=False):
    global message_text, message_index, next_message_frame
    global message_duration, message_is_mode_announcement
    message_text = text
    message_index = 0
    message_duration = duration
    message_is_mode_announcement = mode_announcement
    next_message_frame = time.monotonic()


def update_message(now):
    global message_text, message_index, next_message_frame, display_state
    global message_is_mode_announcement
    if message_text is None or now < next_message_frame:
        return
    frame_count = scrolling_frame_count(geometry, message_text)
    output_count = max(1, int(message_duration * config.MESSAGE_TEXT_FPS))
    frame_index = min(
        frame_count - 1,
        message_index * frame_count
        // (output_count * config.MESSAGE_SCROLL_SLOWDOWN),
    )
    show_frame(scrolling_frame_at(geometry, message_text, frame_index))
    message_index += 1
    next_message_frame = now + 1.0 / config.MESSAGE_TEXT_FPS
    if message_index >= output_count:
        was_mode_announcement = message_is_mode_announcement
        message_text = None
        message_index = 0
        message_is_mode_announcement = False
        if was_mode_announcement:
            render_current_mode(now)
        else:
            show_frame(blank_frame(geometry))
            display_state = protocol.DISPLAY_OFF


def eye_lit(x, y, pupil_x=3):
    local_x = x % config.EYES_MODULE_WIDTH
    if local_x >= 8 or y < 2 or y >= 14:
        return False
    if y in (1, 14):
        outline = 2 <= local_x <= 5
    elif y in (2, 3, 12, 13):
        outline = 1 <= local_x <= 6
    else:
        outline = True
    pupil = pupil_x <= local_x < pupil_x + 2 and 6 <= y <= 9
    return outline and not pupil


def mouth_lit(x, y, level=0):
    if x % 4 == 3:
        return False
    distance = abs(x - ((geometry.width - 1) / 2))
    reach = max(0, level - int(distance // 2))
    upper = max(0, 3 - reach)
    lower = min(geometry.height - 1, 7 + reach)
    return y not in (upper, lower)


def bender_frame(content_id=0):
    frame = blank_frame(geometry)
    for y in range(geometry.height):
        for x in range(geometry.width):
            if module_type == protocol.MODULE_EYES:
                pupil_x = {2: 1, 3: 5}.get(content_id, 3)
                lit = eye_lit(x, y, pupil_x)
            else:
                lit = mouth_lit(x, y, min(4, content_id))
            if lit:
                frame[y * geometry.width + x] = 1
    return frame


def render_current_mode(now=None):
    global display_state
    if modes.mode == protocol.LOCAL_TARGET:
        show_frame(blank_frame(geometry))
        display_state = protocol.DISPLAY_OFF
    elif modes.mode == protocol.LOCAL_TEST:
        update_test(time.monotonic() if now is None else now, force=True)
        display_state = protocol.DISPLAY_LOCAL_TEST
    else:
        show_packed_frame(catalog_frames[catalog_normal_frame])
        display_state = protocol.DISPLAY_NORMAL


def start_animation(animation_id, now, local=False):
    global animation_frames, animation_index, next_animation_frame
    global active_content_id, display_state, activity_state
    animation_frames = animation_sequence(catalog_animations[animation_id])
    animation_index = 0
    next_animation_frame = now + 1.0 / catalog.DEFAULT_ANIMATION_FPS
    active_content_id = animation_id
    display_state = protocol.DISPLAY_ANIMATION
    activity_state = protocol.ACTIVITY_RUNNING
    show_packed_frame(catalog_frames[animation_frames[0]])
    log("LOCAL" if local else "RX", "PLAY ANIMATION", animation_id,
        catalog_animations[animation_id][0])
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

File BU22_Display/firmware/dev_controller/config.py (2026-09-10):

"""Rev D stable development-controller configuration."""

import board

LOGGING = False
MIRROR_I2C = False

I2C_SCL = board.RX
I2C_SDA = board.TX
ADDRESS_PIN = board.A3
MODE_BUTTON = board.MISO
BUFFER_ENABLE = board.MOSI

# Validated half-array hardware SPI1 path: CH5 clock plus CH6 data.
DISPLAY_CLOCK = board.A0
DISPLAY_DATA = board.A1
SPI_BAUDRATE = 4_000_000

EYES_ADDRESS = 0x30
MOUTH_ADDRESS = 0x31
SPARE_ADDRESS = 0x32
DEVELOPMENT_ADDRESS = 0x33
BOTH_A0_THRESHOLD = 29_500
A0_A1_THRESHOLD = 38_200
A1_OPEN_THRESHOLD = 54_600

EYES_MODULE_COUNT = 2
EYES_MODULE_WIDTH = 9
EYES_MODULE_HEIGHT = 16
MOUTH_MODULE_COUNT = 3
MOUTH_MODULE_WIDTH = 5
MOUTH_MODULE_HEIGHT = 11

BRIGHTNESS = 0.08
BENDER_COLOR = (255, 110, 0)
STARTUP_DARK_SECONDS = 3.0
STARTUP_MESSAGE_SECONDS = 2.0
STARTUP_IDENTITY_SECONDS = 2.0
STARTUP_TEXT_FPS = 20
MESSAGE_TEXT_FPS = 10
MESSAGE_SCROLL_SLOWDOWN = 1
MODE_ANNOUNCEMENT_SECONDS = 3.0
FRAME_RATE = 10
MIN_BENDER_PAUSE_SECONDS = 1.0
MAX_BENDER_PAUSE_SECONDS = 4.0
BUTTON_DEBOUNCE_SECONDS = 0.05

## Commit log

2026-08-13 Initial Bending Unit 22 firmware milestone
    [animations.csv, expressions.csv, performances.csv]
2026-08-29 Add BU22 hardware designs and bring-up workflow
    [BOM.csv, BU-22-Display-Controller-Rev-B-BOM.csv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]
2026-08-29 Align Brain button order and heartbeat color
2026-08-29 Correct observed Brain button offset
    [config.py]
2026-08-29 Add numbered Audio FX track testing
2026-08-29 Add live VCNL4200 sensor monitor
2026-08-29 Configure VCNL4200 proximity interrupt test
2026-08-29 Record VCNL4200 close interrupt assertion
2026-08-29 Isolate VCNL4200 close interrupt test
2026-08-29 Add VCNL4200 interrupt acknowledgement command
2026-08-29 Add explicit antenna color test
2026-08-29 Record red antenna output test
2026-08-29 Record sensor clear and antenna output results
2026-08-29 Record Brain power isolation tests
2026-08-29 Add jumper-addressed Rev D I2C target test
2026-08-29 Localize CH4 faults to series resistors
2026-08-29 Record suspected CH4 solder-pad opens
2026-08-29 Record missing U1 supply voltage
2026-09-07 Measure eye tile animation frame rate
2026-09-07 Test reversed clock data on channels 1 through 4
    [code.py, config.py]
2026-09-07 Correct Rev D channel clock data mapping
    [code.py, config.py]
2026-09-09 Record integrated four-device I2C scan
2026-09-09 Add static Eyes and Mouth I2C controls
2026-09-10 Correct Rev D channel order and add array test
    [code.py, config.py]
2026-09-10 Add button-driven Rev D development runtime
